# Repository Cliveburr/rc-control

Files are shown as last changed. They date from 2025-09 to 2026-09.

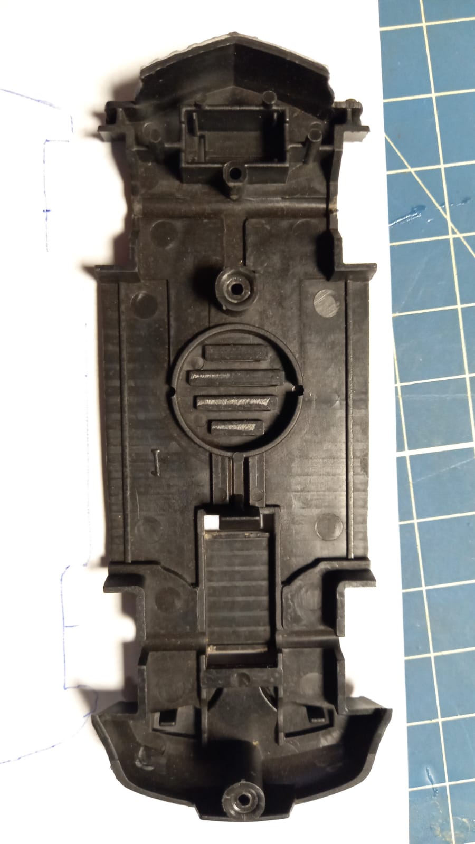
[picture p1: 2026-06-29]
blue-car-1_32/carcass_origin_real.jpeg

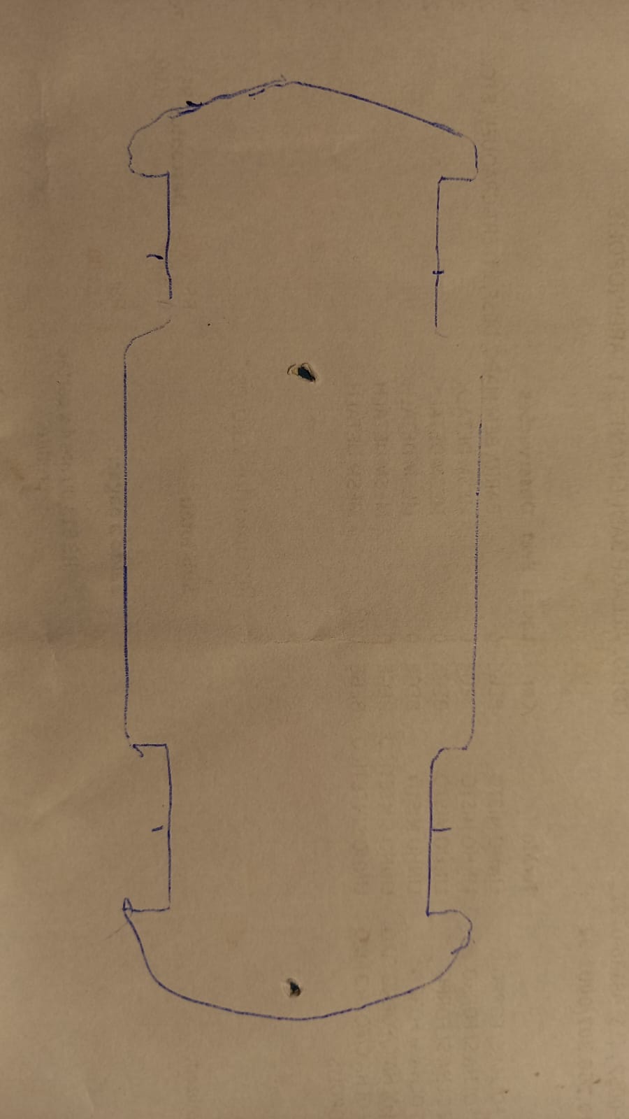
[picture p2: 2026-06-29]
blue-car-1_32/carcass_origin.jpeg

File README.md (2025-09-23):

# RC Control - Projeto ESP32 com Protocolo RCP Binário

## Protocolo RCP (RC Control Protocol)

O sistema utiliza **exclusivamente** o protocolo binário RCP para máxima performance:

- **4 bytes por comando** (vs 28 bytes JSON)
- **98% mais rápido** no processamento (10µs vs 500µs)
- **86% menos dados** transmitidos
- **Validação CRC8** para detecção de erros
- **WebSocket binário puro** sem fallbacks

## Funcionalidades

- ✅ Conexão WiFi (AP mode ou Station mode)
- ✅ Interface Web hospedada no ESP32
- ✅ Transmissão de vídeo via streaming
- ✅ **Sistema OTA (Over-The-Air) para atualizações de firmware**
- ✅ Configuração via interface web
- ✅ Armazenamento de configurações em memória não volátil

## Funcionalidades OTA Implementadas

### Configuração de Partições
- Partições configuradas para suportar OTA com rollback automático
- Duas partições de aplicação (ota_0 e ota_1) para atualizações seguras
- Partição otadata para controle do sistema OTA

### Interface Web para OTA
- **Aba OTA na configuração:** Acesse através do botão de configuração
- **Status do sistema:** Mostra partição atual em execução
- **Upload de firmware:** Envio de arquivos .bin através da interface web
- **Barra de progresso:** Acompanhamento visual do upload
- **Validação automática:** Verificação de integridade do firmware

### Endpoints HTTP para OTA
- `GET /ota/status` - Retorna informações sobre o estado atual das partições
- `POST /ota/upload` - Recebe e instala novo firmware

### Segurança e Rollback
- Rollback automático habilitado em caso de falha na inicialização
- Validação de firmware antes da instalação
- Reinicialização automática após atualização bem-sucedida

## Como Usar o Sistema OTA

1. **Acesse a interface web** do ESP32 através do navegador
2. **Clique no botão de configuração** (primeiro botão superior)
3. **Selecione a aba "OTA"** no menu lateral
4. **Verifique o status atual** do sistema
5. **Selecione o arquivo .bin** do novo firmware
6. **Clique em "Atualizar Firmware"** para iniciar o processo
7. **Aguarde o upload** (barra de progresso será exibida)
8. **O dispositivo reiniciará automaticamente** após a atualização

## Estrutura do Projeto

### Frontend (`/dev_html`)
- `index.html` - Interface principal com controles e configuração
- `script.js` - Lógica JavaScript incluindo funcionalidades OTA
- `style.css` - Estilos da interface
- `prod.js` - Script para gerar versão otimizada

### Backend ESP32 (`/main`)
- `src/main.c` - Inicialização do sistema e OTA
- `src/ota.c` - Implementação completa do sistema OTA
- `src/http_server.c` - Servidor web com endpoints OTA
- `src/config.c` - Gerenciamento de configurações
- `src/net.c` - Configuração de rede WiFi
- `inc/ota.h` - Definições do sistema OTA

## Compilação e Flash

```bash
# Configurar ambiente ESP-IDF
idf.py build

# Flash inicial (primeira vez)
idf.py flash

# Atualizações subsequentes podem ser feitas via OTA através da interface web
```

## Tarefas Completadas

- ✅ Salvar dados em memória não volátil
- ✅ Configurar WiFi (AP e Station mode)
- ✅ Servir HTML e WebSocket
- ✅ Transmitir vídeo via HTTP streaming
- ✅ **Sistema OTA completo com interface web**
- ✅ **Configuração de partições para OTA**
- ✅ **Upload de firmware via browser**
- ✅ **Rollback automático em caso de falha**

## Próximos Passos

- Melhorar qualidade da imagem
- Implementar controles de movimento
- Adicionar autenticação para OTA
- Logs detalhados do processo OTA

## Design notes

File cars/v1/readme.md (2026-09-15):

Versao v1 de chassis controlado por radio tradicional, 15 cm de comprimento, sem amortecedor, com o maximo de partes imprimiveis e usando componentes RC convencionais.

## Premissas da v1

- Comprimento alvo do chassi: 150 mm
- Arquitetura: full RC tradicional
- Alimentacao: LiPo 2S
- Direcao por servo padrao micro
- Tracao traseira simples
- Maximo de partes impressas, usando metal apenas onde faz sentido mecanico

## Arquitetura recomendada

### Conjunto base
- Radio: FlySky FS-I6X
- Receptor: micro receiver compativel com AFHDS 2A, 3 a 6 canais
- Motor: brushed tamanho 130, tensao 6 V a 7.4 V, eixo 2.0 mm
- ESC: brushed automotivo 2S com reverso e BEC 5 V integrado
- Servo: micro servo 5 V, entre 5 g e 9 g, torque minimo de 1.5 kg.cm
- Bateria: LiPo 2S de 450 mAh a 850 mAh
- Rolamentos: MR52ZZ, 2 x 5 x 2.5 mm
- Eixo traseiro: aco 2 mm
- Parafusos: M2 como padrao principal, M3 nos pontos estruturais

## Levantamento de componentes

### 1. Componentes principais

#### Motor de tracao
- Tipo: brushed tamanho 130
- Tensao de trabalho: 6.0 V a 7.4 V
- Tensao maxima: 8.4 V
- Eixo: 2.0 mm
- Faixa de corrente do conjunto: usar ESC de 10 A a 20 A
- Termo de busca: 130 brushed motor 8.4V 12000rpm

- Decidido:
MABUCHI FC-130RA-10300 Small 130 Motor DC 5V-12V 6V 9V High Speed18000RPM Micro 20mm Electric Motor DIY RC Toy Car Boat Model
https://pt.aliexpress.com/item/1005009147508182.html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

#### ESC
- Tipo: ESC brushed para carro
- Alimentacao: LiPo 2S
- Corrente continua: 10 A a 20 A
- Funcoes: frente, re, freio
- BEC integrado: 5 V
- Corrente minima do BEC: 1 A
- Termo de busca: brushed ESC 2S 10A reverse brake 5V BEC

- Decidido:
Mini ESC Brushed Electric Speed Controller ESC Brush Electronic Motor Speed Controller Module 30A 4-8V For RC Car
https://pt.aliexpress.com/item/1005009648276627.html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

#### Servo de direcao
- Alimentacao: 5 V
- Peso: 5 g a 9 g
- Torque minimo: 1.5 kg.cm
- Torque ideal: 1.8 kg.cm a 2.5 kg.cm
- Velocidade: 0.10 s a 0.14 s por 60 graus
- Tipo de engrenagem: nylon ou metal
- Termo de busca: 5V micro servo 9g 2kg

- Decidido:
MG90S Servo 1/4/10 Pcs Metal Gear Digital 9g Servo For RC Helicopter Airplane Boat Car RC Robot
https://pt.aliexpress.com/item/1005006860780474.html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

#### Bateria
- Tipo: LiPo 2S
- Tensao nominal: 7.4 V
- Tensao maxima: 8.4 V
- Capacidade recomendada: 650 mAh a 850 mAh
- Taxa de descarga: 30C ou maior
- Conector: XT30
- Termo de busca: 2S LiPo 850mAh 30C XT30

#### Receptor
- Tipo: micro receiver compativel com FlySky AFHDS 2A
- Canais: 3 a 6
- Alimentacao: 4.8 V a 6.0 V pelo BEC do ESC
- Saida: PWM padrao RC
- Quantidade para compra: 1 unidade
- Termo de busca: FlySky AFHDS 2A micro receiver

#### Rolamentos
- Modelo: MR52ZZ
- Medida: 2 x 5 x 2.5 mm
- Tipo: blindado metal
- Uso previsto: eixo traseiro e pivots dianteiros
- Quantidade minima para compra: 10 unidades
- Quantidade mais segura: 20 unidades
- Termo de busca: MR52ZZ 2x5x2.5mm bearing

### 2. Itens mecanicos muito provaveis

#### Eixos
- Eixo traseiro: haste de aco 2 mm
- Linkagens: haste de 1.0 mm a 1.2 mm

#### Engrenagens
- Pinhao: modulo 0.5, 10T a 12T, furo 2.0 mm
- Coroa: modulo 0.5, 48T a 64T
- Relacao inicial: 5:1 a 7:1
- Termo de busca: 0.5 mod pinion 2mm bore
- Termo de busca: 0.5 mod spur gear 48T 64T

#### Cubos e fixacao de roda
- Cubos: eixo 2 mm com prisioneiro M2
- Rodas: 22 mm a 26 mm de diametro
- Largura sugerida: 8 mm a 12 mm

#### Linkagem de direcao
- Arame 0.8 mm a 1.2 mm
- Terminal M2 ou dobra tipo Z
- Servo horn compativel com o servo escolhido

### 3. Parafusos e fixadores

Voce ja tem M2 e M3, e para um chassi de 15 cm isso ainda cobre o projeto.

#### O que provavelmente sera usado de verdade
- M2: fixacao do servo, suportes pequenos, manga de eixo, tampa de transmissao, prisioneiros e partes finas impressas
- M3: longarinas, uniao principal do chassi, suporte de bateria, fixacao do ESC e do receptor se houver base mais robusta

#### Comprimentos uteis
- M2 x 4, 6, 8, 10 e 12 mm
- M3 x 6, 8, 10, 12 e 16 mm
- Porcas M2 e M3
- Arruelas M2 e M3
- Insertos roscados pequenos para plastico, se quiser manutencao melhor

## Regulacao de tensao

- Receptor: 5 V pelo BEC do ESC
- Servo: 5 V pelo BEC do ESC
- Regulador extra: nao necessario se o ESC tiver BEC integrado

## Lista de compra recomendada

### Comprar agora
- 2 a 3 motores brushed tamanho 130 para 2S, eixo 2.0 mm
- 1 a 2 ESCs brushed 2S com reverso e BEC 5 V
- 2 micro servos 5 V entre 5 g e 9 g, acima de 1.5 kg.cm
- 2 a 3 baterias LiPo 2S entre 650 mAh e 850 mAh, 30C ou maior, com XT30
- 1 micro receiver compativel com FlySky AFHDS 2A
- 10 a 20 rolamentos MR52ZZ 2 x 5 x 2.5 mm
- 2 hastes de aco 2 mm
- 1 kit de pinhoes 0.5M para eixo 2.0 mm
- 1 kit de coroas 0.5M 48T a 64T
- 1 jogo de cubos de roda para eixo 2 mm com prisioneiro M2
- 1 conjunto de linkagem de direcao 0.8 mm a 1.2 mm
- 1 jogo de conectores XT30 e fio de silicone 20 AWG a 24 AWG

### Comprar so se faltar no estoque
- Porcas M2 e M3
- Arruelas M2 e M3
- Parafusos M2 curtos em varios comprimentos
- Parafusos M3 medio e longos
- Espacadores plastico ou metal
- Servo horn extra

## BOM base

- FlySky FS-I6X
- Micro receiver compativel com AFHDS 2A
- Motor brushed tamanho 130, eixo 2.0 mm
- ESC brushed 2S com reverso e BEC 5 V
- Micro servo 5 V entre 5 g e 9 g
- Bateria LiPo 2S 650 mAh a 850 mAh com XT30
- Rolamentos MR52ZZ 2 x 5 x 2.5 mm
- Eixo de aco 2 mm
- Pinhao 0.5M 10T a 12T, furo 2.0 mm
- Coroa 0.5M 48T a 64T
- Cubos de roda 2 mm com prisioneiro M2
- Rodas 22 mm a 26 mm
- Linkagem 0.8 mm a 1.2 mm
- Parafusos M2 e M3

- Pneu(Tire)
- Roda(Wheel), tem q ter o furo central e o encaixe xegagonal para encaixar no cubo da roda
- Cubo da roda(WheelHub), da suporte para a rosca da roda, o eixo de roda passa por ela e ela fica encostada com espaçador no rolamento do manga do eixo
- Manga do eixo(SteeringKnuckle)
- HubCarrier

V1

Eixo 2mm
Rolamento 2x5x2.5mm

- Comprar cossinete 2mm

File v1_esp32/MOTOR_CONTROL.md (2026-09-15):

# Motor Control System Documentation

## Overview

This document describes the motor control system implemented for the RC Control project. The system provides a Hardware Abstraction Layer (HAL) that supports multiple motor drivers with easy driver switching.

## Features

- **Hardware Abstraction Layer (HAL)**: Easily switch between different motor drivers
- **DRV8833 Driver**: Full implementation with PWM control
- **Multiple Control Modes**: Forward, Reverse, Brake, and Free running
- **Speed Control**: -100 to +100 range (full reverse to full forward)
- **Web Interface Integration**: Control via HTTP commands
- **Status Monitoring**: Real-time motor state via system info endpoint
- **Configurable Parameters**: GPIO pins, PWM settings, and control modes

## Architecture

### Motor Control HAL (`motor_control.h/c`)

The main HAL provides a unified interface for all motor drivers:

```c
// Initialize motor control system
esp_err_t motor_control_init(void);

// Set motor speed (-100 to +100)
esp_err_t motor_control_set_speed(int speed);

// Set motor mode directly
esp_err_t motor_control_set_mode(motor_mode_t mode);

// Stop motor immediately
esp_err_t motor_control_stop(void);

// Get current motor state
esp_err_t motor_control_get_state(motor_state_t *state);
```

### DRV8833 Driver (`motor_drv8833.h/c`)

Specific implementation for DRV8833 dual H-bridge motor driver:

- **GPIO Pins**: GPIO16 (IN1), GPIO17 (IN2)
- **PWM Frequency**: 1kHz (configurable)
- **Resolution**: 10-bit (0-1023)
- **Control Method**: Direct PWM on IN1/IN2 pins

## Configuration

### Hardware Configuration (`motor_drv8833.h`)

```c
// GPIO pins for DRV8833
#define DRV8833_IN1_PIN         16  // GPIO16 for IN1
#define DRV8833_IN2_PIN         17  // GPIO17 for IN2

// PWM configuration
#define DRV8833_LEDC_FREQUENCY      1000                // 1kHz PWM frequency
#define DRV8833_LEDC_DUTY_RES       LEDC_TIMER_10_BIT   // 10-bit resolution

// Control modes
#define DRV8833_BRAKE_MODE_HIGH     1  // 1 = IN1=HIGH, IN2=HIGH for brake
#define DRV8833_FREE_MODE_LOW       1  // 1 = IN1=LOW, IN2=LOW for free
```

### Driver Selection (`motor_control.h`)

```c
// Change this to switch motor drivers
#define MOTOR_ACTIVE_DRIVER     MOTOR_DRIVER_DRV8833
```

## Motor Control Modes

| Mode | Description | DRV8833 Configuration |
|---|---|---|
| **MOTOR_MODE_FORWARD** | Motor rotating forward | IN1=PWM, IN2=LOW |
| **MOTOR_MODE_REVERSE** | Motor rotating in reverse | IN1=LOW, IN2=PWM |
| **MOTOR_MODE_BRAKE** | Motor braking (short circuit) | IN1=HIGH, IN2=HIGH |
| **MOTOR_MODE_FREE** | Motor free running (no power) | IN1=LOW, IN2=LOW |

## Web Interface Integration

### Speed Control Command

The motor responds to speed commands sent via WebSocket:

```json
{
  "command": "speed",
  "value": 75
}
```

Where `value` ranges from -100 to +100:
- **-100**: Full reverse
- **0**: Stop (brake mode)
- **+100**: Full forward

### System Status

Motor status is included in the `/api/system/info` endpoint:

```json
{
  "motor": {
    "enabled": true,
    "speed": 75,
    "mode": 0,
    "mode_str": "forward",
    "active": true
  }
}
```

## Usage Examples

### Basic Motor Control

```c
#include "motor_control.h"

void app_main(void) {
    // Initialize motor control
    motor_control_init();
    
    // Set forward speed at 50%
    motor_control_set_speed(50);
    
    // Wait 2 seconds
    vTaskDelay(2000 / portTICK_PERIOD_MS);
    
    // Set reverse speed at 30%
    motor_control_set_speed(-30);
    
    // Wait 2 seconds
    vTaskDelay(2000 / portTICK_PERIOD_MS);
    
    // Stop motor
    motor_control_stop();
}
```

### Direct Mode Control

```c
// Set motor to free running mode
motor_control_set_mode(MOTOR_MODE_FREE);

// Set motor to brake mode
motor_control_set_mode(MOTOR_MODE_BRAKE);
```

### Get Motor Status

```c
motor_state_t state;
if (motor_control_get_state(&state) == ESP_OK) {
    printf("Speed: %d, Mode: %d, Enabled: %s\n", 
           state.speed, state.mode, state.enabled ? "Yes" : "No");
}
```

## Adding New Motor Drivers

To add support for a new motor driver (e.g., L298N):

1. **Create header file**: `motor_l298n.h`
2. **Create implementation**: `motor_l298n.c`
3. **Implement driver interface**:
   ```c
   const motor_driver_interface_t* l298n_get_interface(void);
   ```
4. **Add driver type**: Add `MOTOR_DRIVER_L298N` to `motor_driver_type_t`
5. **Update driver selection**: Modify `MOTOR_ACTIVE_DRIVER` in `motor_control.h`

## Pin Usage Summary

| Component | GPIO | Function |
|---|---|---|
| Motor IN1 | GPIO16 | PWM control (DRV8833) |
| Motor IN2 | GPIO17 | PWM control (DRV8833) |
| Servo | GPIO4 | PWM control |
| LED Light | GPIO2 | Digital output |
| LED Horn | GPIO14 | Digital output |
| Battery Monitor | GPIO34 | ADC input |

## Troubleshooting

### Motor Not Responding

1. Check `ENABLE_MOTOR_CONTROL` is set to 1 in `project_config.h`
2. Verify GPIO pins are not conflicting with other peripherals
3. Check motor driver initialization in serial output
4. Verify motor driver power supply

### Compilation Errors

1. Ensure all header files are included properly
2. Check driver selection configuration
3. Verify ESP-IDF version compatibility

### Performance Issues

1. Adjust PWM frequency in driver configuration
2. Check for GPIO conflicts
3. Monitor system load and memory usage

## Future Enhancements

- **Multiple Motor Support**: Extend HAL for multiple motors
- **Encoder Feedback**: Add position/speed feedback
- **PID Control**: Implement closed-loop control
- **Safety Features**: Current limiting, thermal protection
- **Additional Drivers**: L298N, TB6612FNG, etc.

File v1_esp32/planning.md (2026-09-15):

Projeto ESP32 para controle de carro/drone/aviação remoto.

- Conexão por Wifi ou Bluetooth
- Update do firmware por OTA (Over the Air)
- View em HTML hospedada no proprio ESP32
- Comandos via Websocket

Projeto Html:
    Folder: /dev_html
    - Todo HTML deve ficar no único arquivo "index.html"
    - Todo javascript deve ficar no único arquivo "script.js"
    - Todo CSS deve ficar no único arquivo "style.css"
    - Maxima otimização do JS e CSS
    - Preparado para Landscape mode

Project ESP32:
    Folder: /main
    - Arquivo /main/wwwroot/index.html é gerado pelo script "\dev_html> node run prod"
    - O OTA vai ser enviado pelo HTML
    - Os LED devem sempre estar configurado no modo Sinking (Dreno de corrente – Negativo direto no LED)

Views:
    Main:
        Divisão por colunas
            Primeira coluna um botão de controle de velocidade do lado esquerdo
            Resto das colunas
                Divisão por linhas
                    Linha do topo para botões
                        Sequencia de botões de uso geral
                        No canto esquero um botão abre tela de configuração
                    Linha alinha abaixo
                        Botão de controle de direção alinhado a direita

    Configuration:
        Card - Configuration
        No body um tab com itens a esquerda, itens:
            General
            Wifi
            OTA
        Tab General:
            Botão de escolha da conexão, Bluetooth ou WIFI
        Tab Wifi:
            Campo para entrar o nome do WIFI
            Campo para entrar a senha do WIFI
            Botão para Gravar
        Tab OTA:
            Botão para selecionar o arquivo .bin para fazer upload
            Botão para Atualizar

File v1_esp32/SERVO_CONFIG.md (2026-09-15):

# Configuração do Servo GH-S37D

## Conexões GPIO

### Servo GH-S37D (3.7g Mini Micro Servo)
- **GPIO4** - Sinal de controle PWM do servo
- **3.3V** - Alimentação VCC (compatível com 1S LiPo 3.7V)
- **GND** - Terra comum

### Esquema de Conexão
```
ESP32        GH-S37D Servo
GPIO4   -->  Sinal (amarelo/branco)
3.3V    -->  VCC (vermelho)
GND     -->  GND (marrom/preto)
```

## Especificações Técnicas

### Servo GH-S37D
- **Tensão**: 3.0V - 4.2V (ideal para 1S LiPo)
- **Peso**: 3.7g
- **Torque**: ~0.8kg.cm
- **Velocidade**: ~0.10s/60°
- **Controle**: PWM padrão (50Hz, 1-2ms pulse width)

### Configuração PWM
- **Frequência**: 50Hz (período de 20ms)
- **Largura de pulso**:
  - 1.0ms = mínimo configurado
  - 1.5ms = centro
  - 2.0ms = máximo configurado
- **Importante**: esses pulsos definem o range elétrico enviado ao servo. O ângulo mecânico real depende do modelo do servo, da tensão e da linkagem. Em muitos microservos, 1.0-2.0ms resulta em algo perto de 90° totais, ou cerca de 45° para cada lado a partir do centro.
- **Resolução**: 13 bits (8192 níveis)
- **Timer LEDC**: TIMER_1
- **Canal LEDC**: CHANNEL_1

## Comando de Controle

### Via WebSocket
```json
{
  "type": "wheels",
  "value": 0
}
```

**Valores do comando:**
- `-100` = pulso mínimo configurado
- `0` = centro
- `+100` = pulso máximo configurado

### Função de Controle
```c
esp_err_t servo_control_set_position(int position);
```

**Parâmetros:**
- `position`: Valor entre -100 e +100
- **Retorno**: `ESP_OK` se bem-sucedido

## Instalação Física

### Montagem
1. Fixar o servo na estrutura do chassi usando parafusos M2
2. Conectar o braço servo (servo horn) ao sistema de direção
3. Ajustar linkagem para que posição central corresponda a rodas retas

### Linkagem de Direção
- Use barras de ligação rígidas (pushrods) de 0.8-1.0mm
- Terminais esféricos (ball links) M2 para conexões articuladas
- Comprimento da linkagem deve permitir curso completo sem travamento

### Alimentação
- O servo pode ser alimentado diretamente da bateria 1S LiPo (3.7V)
- Consumo típico: 50-150mA em operação normal
- Pico de corrente: até 500mA durante movimento rápido

## Calibração

### Valores de Trim
Se necessário ajustar o centro mecânico:
1. Modificar `SERVO_CENTER_PULSE_WIDTH` em `servo_control.h`
2. Valores típicos: 1450-1550μs dependendo do servo

### Limitação de Curso
Para evitar danos mecânicos:
1. Ajustar `SERVO_MIN_PULSE_WIDTH` e `SERVO_MAX_PULSE_WIDTH`
2. Testar movimento completo antes de finalizar montagem
3. Confirmar o curso real do servo antes de assumir 180° totais com 1.0-2.0ms

## Troubleshooting

### Servo não responde
- Verificar conexões GPIO4, 3.3V e GND
- Confirmar tensão de alimentação (3.0-4.2V)
- Verificar logs no monitor serial

### Movimento irregular
- Verificar interferência eletromagnética
- Adicionar capacitor de filtro (100μF) na alimentação
- Afastar fios do servo dos fios do motor principal

### Consumo excessivo
- Verificar se linkagem não está travando
- Reduzir carga mecânica no servo
- Verificar alinhamento das peças móveis

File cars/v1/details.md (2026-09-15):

manga de eixo
cubo da roda
mancal do eixo
stub axle ou eixo fixo da roda na dianteira
Se eu fosse fechar a arquitetura agora, eu faria assim:

Traseira: 2x MR52ZZ no chassi, eixo de 2 mm, cubo preso no eixo, roda parafusada no cubo.
Dianteira: 2x MR52ZZ por roda, dentro do cubo da roda, girando em um eixo fixo preso na manga de eixo.

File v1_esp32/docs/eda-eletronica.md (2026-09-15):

https://kicad.org/download

Extensões de diagrama no VSCODE

Draw.io (hediet.vscode-drawio)
Comunidade: Muito grande — diagrams.net é amplamente usado; a extensão do Hediet é popular (repositório com milhares de stars).
Maturidade: Madura e estável, pensada para diagramas e documentação.
Atividade: Repositório ativo, releases e CI; mantém atualizações periódicas.
Componentes: Biblioteca de símbolos elétricos disponível; você pode importar/colar SVGs ou criar símbolos para ESP32, drivers e buck converters, mas não há footprint/netlist.
Exportação: PNG, SVG, PDF, XML (.drawio) e .drawio.png com dados embutidos — ótimo para documentação, não para fabricação.
Quando usar: se quer desenhar esquemas e guardar junto ao código no VSCode rapidamente (documentação/diagramas de fiação).

Circuit Diagram (circuitdiagram-vscode / circuit-diagram libraries)
Comunidade: Menor que draw.io; projeto nicho focado em diagramas eletrônicos simples.
Maturidade: Leve e suficiente para diagramas técnicos em docs, não EDA.
Atividade: atividade moderada/irregular (projetos menores).
Componentes: símbolos eletrônicos básicos; customização possível mas biblioteca limitada (ESP32 provavelmente como símbolo genérico).
Exportação: SVG/PNG/HTML; sem netlist nem gerbers.
Quando usar: se prefere diagramas rápidos em texto/markdown ou integração direta com docsites.

KiCad + KiCad Studio (oaslananka/kicad-studio para VS Code)
Comunidade: Muito grande — KiCad é ferramenta EDA open-source padrão; forte comunidade e bibliotecas extensas.
Maturidade: Produção/industrial — adequado para criar esquemáticos e preparar fabricação (PCB).
Atividade: KiCad é ativamente desenvolvido; a extensão KiCad Studio integra o workflow ao VS Code (repositorio separado, evolução mais recente).
Componentes: Bibliotecas extensas (muitos MCU/modules, drivers, conversores). ESP32 e drivers típicos têm símbolos/footprints comunitários; se faltar, cria-se o símbolo/footprint.
Exportação: Netlist, Gerber/Drill, BOM, STEP/3D, formatos industriais — ideal para passar a outro programa ou mandar fabricar.
Quando usar: se pretende, no futuro, fabricar PCBs ou precisar de netlist/BOM — é a opção mais completa (exige instalação do KiCad e curva de aprendizado).

SchemDraw (biblioteca Python)
Comunidade: Nicho (científico/descritivo), menor que opções acima.
Maturidade: Estável para criar imagens via código.
Atividade: mantido, bom para automação de diagramas.
Componentes: Shapes programáticos; dá para representar ESP32/stepper, mas sem footprint/netlist.
Exportação: SVG, PDF, PNG (gerado por script).
Quando usar: se quer gerar diagramas por script/automação (não interativo no VS Code).

Fritzing
Comunidade: Firme na comunidade hobbyista/maker; menos usado profissionalmente.
Maturidade: Fácil para breadboard/diagrama de ligação; UI feita para iniciantes.
Atividade: menor que KiCad; desenvolvimento e manutenção mais lentos.
Componentes: muitas peças comunitárias; ESP32 e módulos hobby geralmente disponíveis ou importáveis.
Exportação: Pode exportar PCB e gerar Gerbers (útil para fabricar), mas as bibliotecas/qualidade de footprints são mais limitadas que KiCad.
Quando usar: protótipos rápidos estilo breadboard e documentação para makers; menos recomendado para produção.
Recomendação curta

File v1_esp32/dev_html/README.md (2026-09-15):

# RC Control - Interface Web com Protocolo RCP Binário Puro

## Sobre a Interface

Esta é a interface web de controle do carrinho RC que utiliza **exclusivamente** o **RCP (RC Control Protocol)** - um protocolo binário customizado para comunicação ultra-eficiente.

## Arquivos

- `index.html` - Interface principal de controle
- `style.css` - Estilos visuais  
- `script.js` - **Lógica JavaScript com RCP Client puro**

## Protocolo RCP Puro

A interface utiliza **APENAS** o protocolo RCP binário:

### ✅ **Performance Ultra-Otimizada:**
- **4 bytes por comando** vs 28 bytes JSON (86% redução)
- **10µs processamento** vs 500µs JSON (98% mais rápido)
- **Validação CRC8** para detecção de erros
- **Protocolo binário puro** - sem fallbacks ou legacy code

### ✅ **Comunicação Limpa:**
```javascript
// Apenas comandos RCP binários
rcpClient.sendMotorCommand(-85);    // 4 bytes
rcpClient.sendServoCommand(45);     // 4 bytes  
rcpClient.sendHornCommand(true);    // 4 bytes
rcpClient.sendLightCommand(false);  // 4 bytes
```

### ✅ **Funções de Debug:**
```javascript
// No console do navegador
showRCPStats(); // Mostra estatísticas do protocolo
```

## Como Testar

1. **Compile e flash o ESP32** com suporte RCP
2. **Conecte na rede WiFi** do ESP32
3. **Acesse** `http://192.168.4.1`
4. **Controle o carrinho** normalmente
5. **Abra F12 Console** e digite `showRCPStats()` para ver performance

## Logs de Conexão

Quando conectar, você verá no console:
```
WebSocket connected for control commands
RCP Client v1.0 initialized
RCP Client initialized and ready
```

## Comandos de Controle

### **Motor (Speed):**
- Controle vertical esquerdo
- Range: -100 (ré máxima) a +100 (frente máxima)
- **RCP**: 4 bytes binários

### **Servo (Wheels):**
- Controle horizontal inferior
- Range: -100 (esquerda máxima) a +100 (direita máxima)  
- **RCP**: 4 bytes binários

### **Horn:**
- Botão de buzina (alto-falante)
- Estados: ON/OFF
- **RCP**: 4 bytes binários

### **Light:**
- Botão de luz (lâmpada)
- Estados: ON/OFF
- **RCP**: 4 bytes binários

## Requisitos do Sistema

### **ESP32:**
- ✅ **Firmware com suporte RCP obrigatório**
- ✅ **Protocolo binário único**
- ❌ **Sem suporte a JSON legacy**

### **Interface Web:**
- ✅ **WebSocket binário obrigatório**
- ✅ **Conectividade automática**
- ❌ **Sem fallback para JSON**

## Monitoramento de Performance

### **Estatísticas em Tempo Real:**
```javascript
// Console do navegador
showRCPStats();

// Saída esperada
=== RCP Protocol Statistics ===
Commands Sent: 1247
Responses Received: 156  
Errors: 0
Success Rate: 100.0%
==============================
```

### **Logs de Debug:**
Para habilitar logs detalhados, altere no `script.js`:
```javascript
const DEBUG = true; // Mostra logs detalhados
```

## Benefícios do RCP

### **Para Usuários:**
- ✅ **Resposta mais rápida** dos controles
- ✅ **Menor latência** na comunicação
- ✅ **Menos problemas** de conectividade
- ✅ **Bateria dura mais** (menos processamento)

## Troubleshooting

### **Conexão não funciona:**
1. Verificar se ESP32 foi compilado com suporte RCP
2. Verificar logs no console: deve aparecer "RCP Client initialized"
3. ESP32 deve ter protocolo RCP compilado (sem JSON legacy)

### **Performance não otimizada:**
1. Verificar `showRCPStats()` - deve mostrar commands sent > 0
2. Verificar se errors = 0
3. Todos os comandos devem ser binários (4 bytes cada)

### **Problemas de conectividade:**
1. RCP inclui validação CRC8 - detecta problemas de rede
2. Reconnect automático mantido
3. Apenas frames binários são aceitos

**O protocolo RCP puro oferece máxima performance sem complexidade de fallbacks!** 🚀

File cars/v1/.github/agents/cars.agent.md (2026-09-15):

---
name: cars
description: Assistente para criação de carro radio controlado impresso 3D
tools: [read/readFile, read/viewImage, edit/createDirectory, edit/createFile, edit/editFiles, search/listDirectory, search/textSearch, web/fetch, freecad/create_document, freecad/create_object, freecad/delete_object, freecad/edit_object, freecad/execute_code, freecad/get_object, freecad/get_objects, freecad/get_parts_list, freecad/get_view, freecad/insert_part_from_library, freecad/list_documents, brave-search/brave_local_search, brave-search/brave_web_search] 'freecad/*']
---

Esta workspace é para criação de modelos de carros radio controlado com o máximo de peças impressa em 3D, seu papel é auxiliar o usuário a resolver os detalhes dos projetos.

Use o documento - [figure_process.md](../../figure_process.md) como centro de informações.

O contéudo dos documentos sempre em Português(PT-BR) porém considere nomenclaturas e palavras chaves em Ingles, assim como as versões tanto do Blender, FreeCAD e do BambuLab Slicer tudo em ingles.

Use o brave_search quando precisar fazer pesquisas pela internet, sempre efetuando apenas uma chamada por vez.

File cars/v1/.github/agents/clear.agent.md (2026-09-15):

---
name: clear
description: Agent limpo para duvidas gerais
tools: [web/fetch, 'brave-search/*']
---

Você é um assistente para responde as duvidas do usuário, seja direto, não proponha alterantivas se não for solicitado.

Use o brave_search quando precisar fazer pesquisas pela internet, sempre efetuando apenas uma chamada por vez.

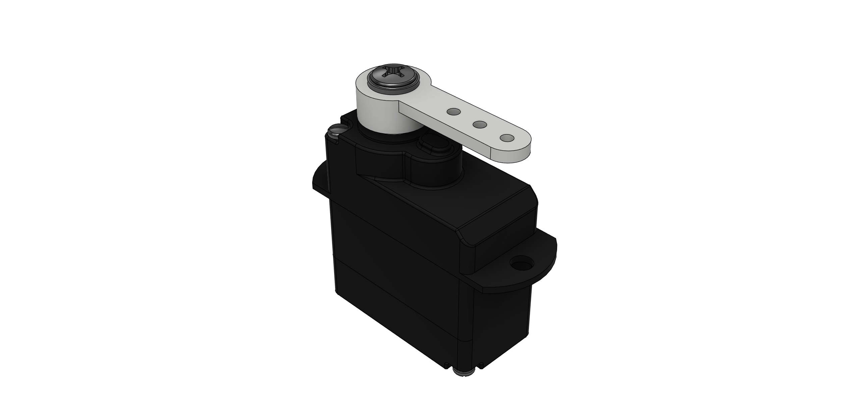
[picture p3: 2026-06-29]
3dmodels/servos/Mini 2g Servo Motor/Mini 2g Servo Motor Top.png

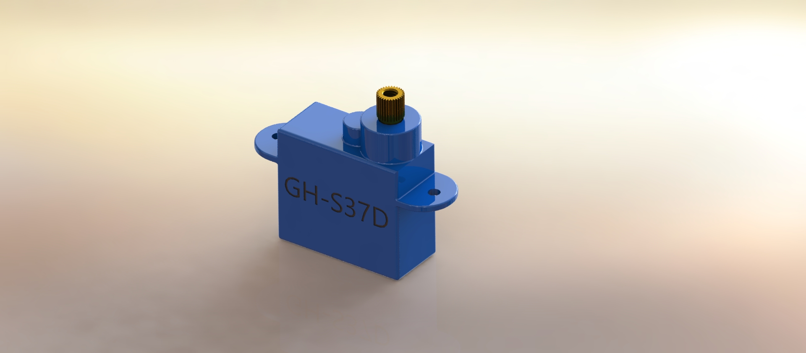
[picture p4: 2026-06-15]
3dmodels/servos/GH-S37D/servo GH-S37D.JPG

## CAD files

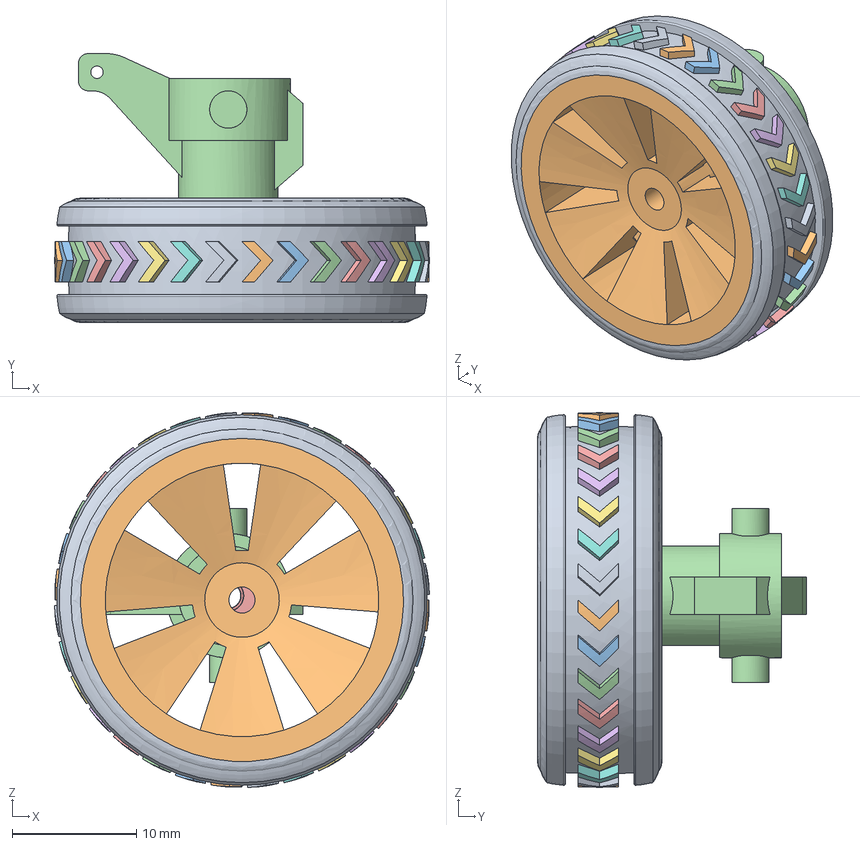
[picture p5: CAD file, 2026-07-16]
cars/v1/chassis/ChassiAssembly.FCStd
30.2 x 21.6 x 30.2 mm
Tire_2a_10l_V1
Tire_2a_10l_V001
Tire_2a_10l_V002
Tire_2a_10l_V003
Tire_2a_10l_V004
Tire_2a_10l_V005
Tire_2a_10l_V006
Tire_2a_10l_V007
Tire_2a_10l_V008
Tire_2a_10l_V009
Tire_2a_10l_V010
Tire_2a_10l_V011
Tire_2a_10l_V012
Tire_2a_10l_V013
Tire_2a_10l_V014
Tire_2a_10l_V015
Tire_2a_10l_V016
Tire_2a_10l_V017
Tire_2a_10l_V018
Tire_2a_10l_V019
Tire_2a_10l_V020
Tire_2a_10l_V021
Tire_2a_10l_V022
Tire_2a_10l_V023
Tire_2a_10l_V024
Tire_2a_10l_V025
Tire_2a_10l_V026
Tire_2a_10l_V027
Tire_2a_10l_V028
Tire_2a_10l_V029
Tire_2a_10l_V030
Tire_2a_10l_V031
Tire_2a_10l_V032
Whells_26d_10l_V1
WhellHubV1
SteeringKnuckleV1
MR52ZZ 2x5x2.5mm

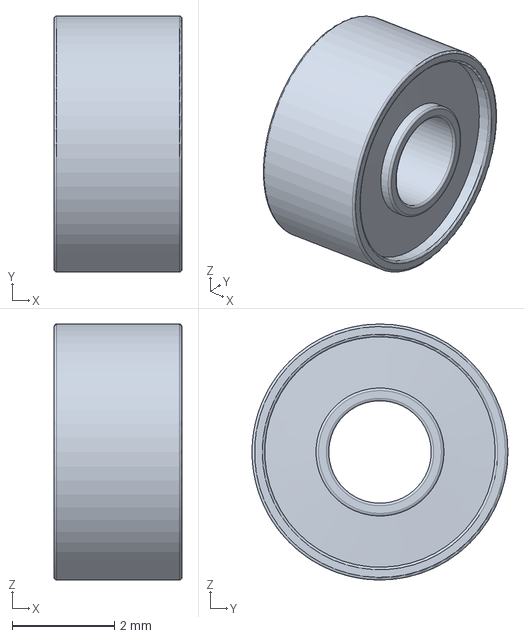
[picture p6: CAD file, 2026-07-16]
3dmodels/bears/MR52ZZ 2x5x2.5mm.FCStd
2.50 x 5.00 x 5.00 mm

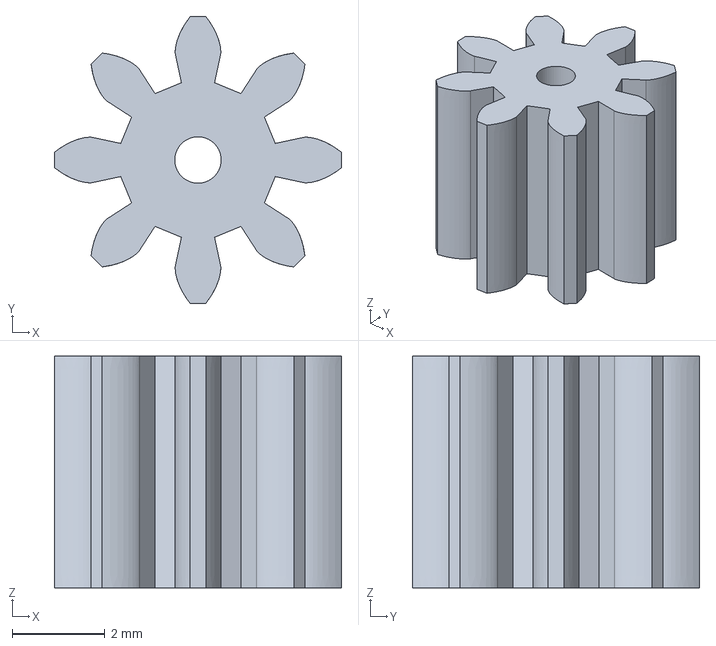
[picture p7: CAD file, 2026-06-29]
3dmodels/gears/GearsModels.FCStd
6.19 x 6.19 x 5.00 mm

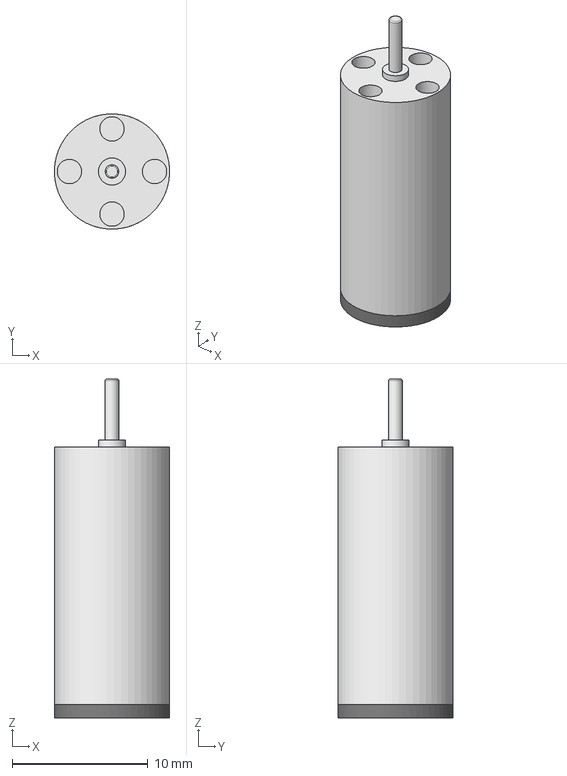
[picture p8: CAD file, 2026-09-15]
3dmodels/motors/8520 Coreless Brshed motor.step
8.50 x 8.50 x 25.0 mm

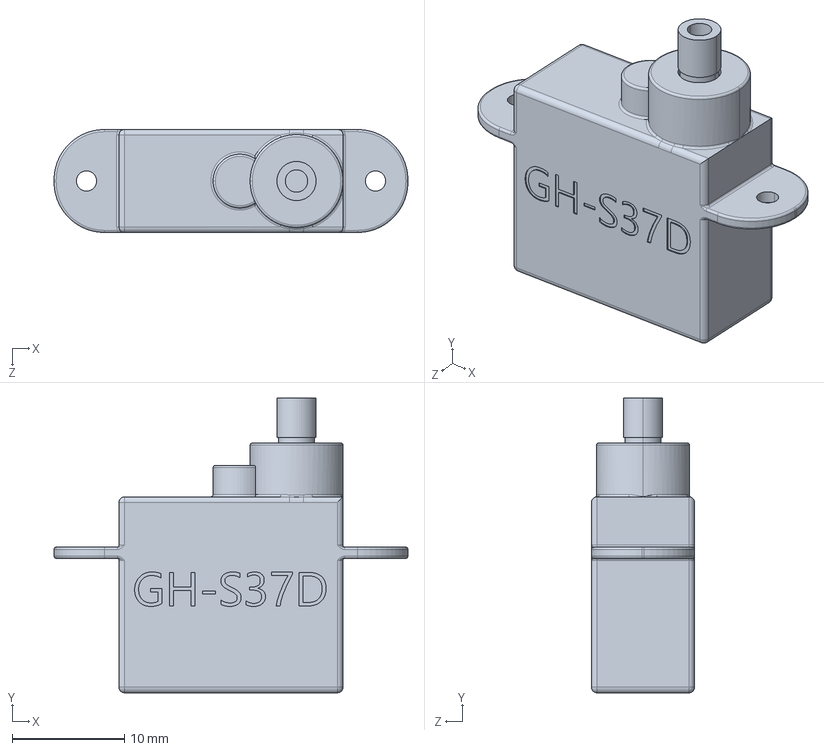
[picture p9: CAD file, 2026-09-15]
3dmodels/servos/GH-S37D/Gh-S37D Servo.STEP
31.6 x 26.3 x 9.20 mm

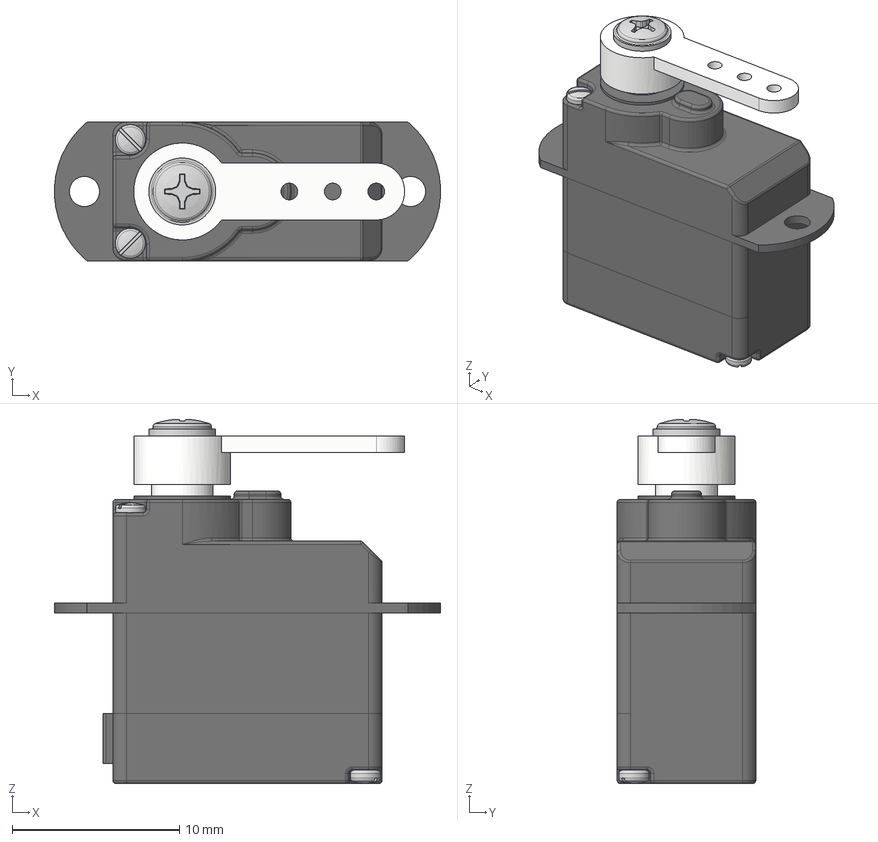
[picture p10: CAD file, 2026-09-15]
3dmodels/servos/Mini 2g Servo Motor/Mini 2g Servo Motor.step
23.1 x 8.30 x 21.8 mm
Shaft
Horn
Screw

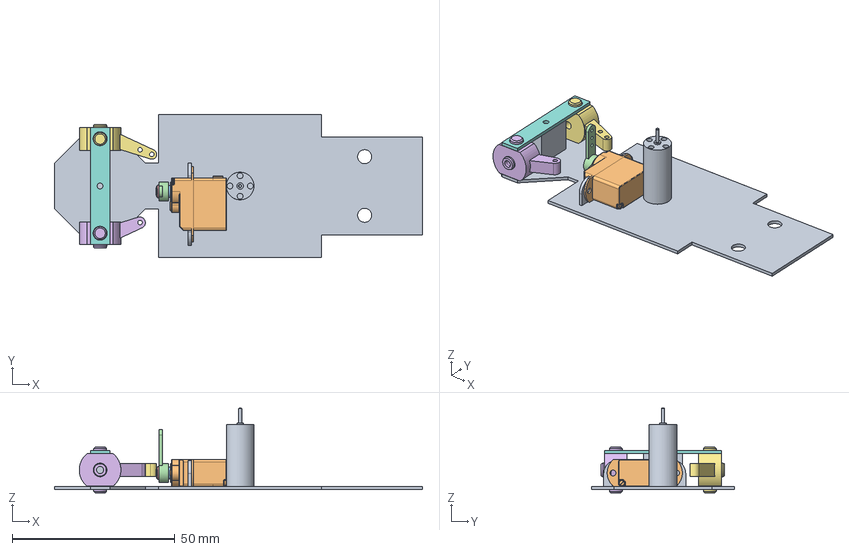
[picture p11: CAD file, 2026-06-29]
blue-car-1_32/BlueCar132Carcass.FCStd
113.0 x 44.0 x 26.0 mm
BaseEncaixe
Shaft
Horn
Screw
CuboDirecaoRodaEsquerda
CuboDirecaoRodaDireita
TampaDirecao
8520 Coreless Motor v3
8520 Coreless Motor v001

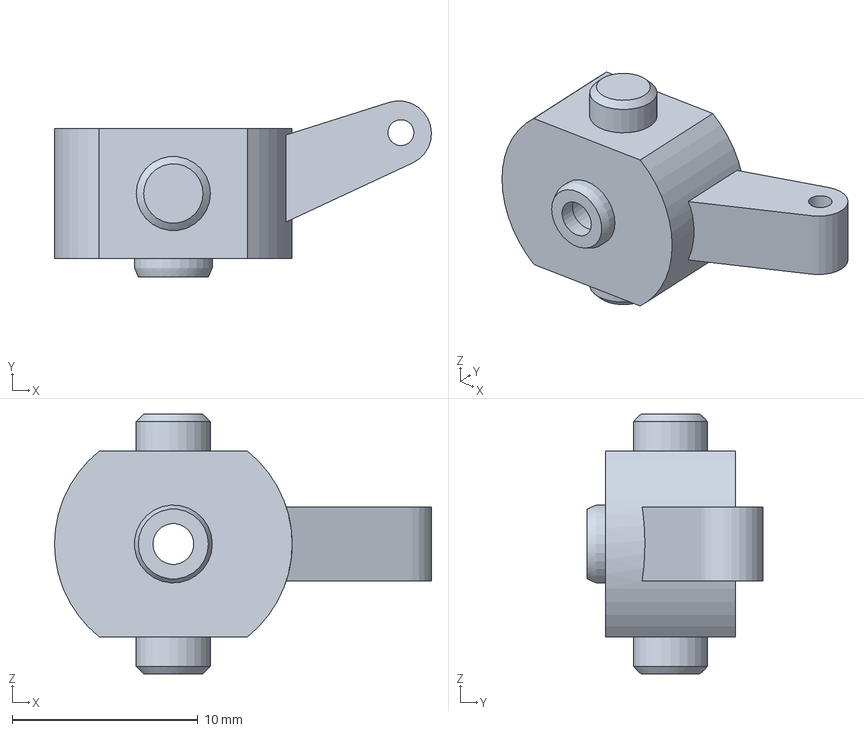
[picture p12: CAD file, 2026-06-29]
blue-car-1_32/prints/BlueCar132Carcass-CuboDirecaoRodaEsquerda.3mf
20.3 x 9.49 x 14.0 mm

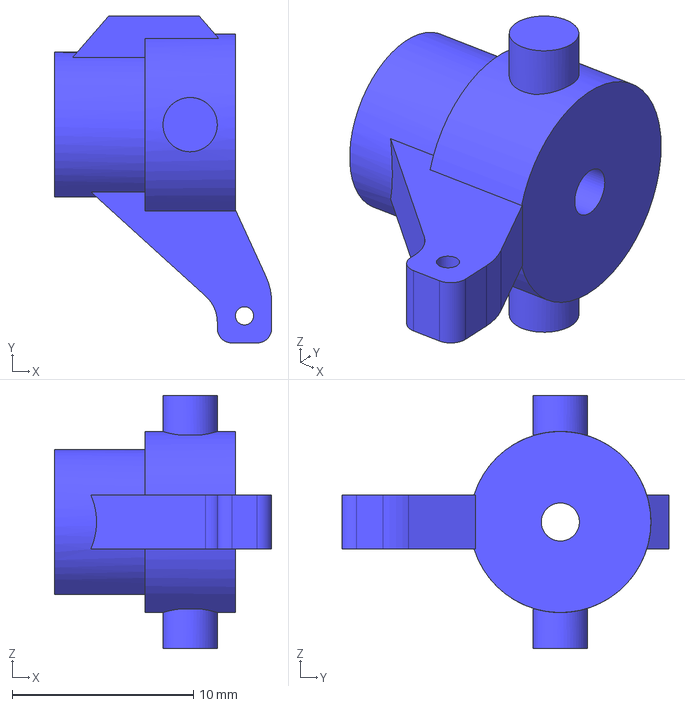
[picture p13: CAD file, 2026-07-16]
cars/v1/chassis/steps/SteeringKnuckle-SteeringKnuckleV1.step
12.0 x 18.1 x 14.0 mm

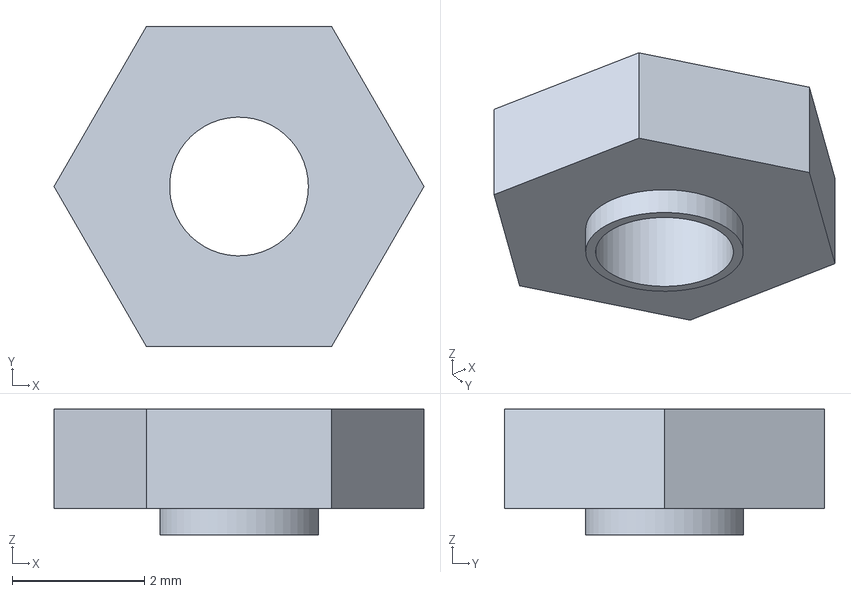
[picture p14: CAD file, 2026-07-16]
cars/v1/chassis/WhellHub.FCStd
5.60 x 4.85 x 1.90 mm

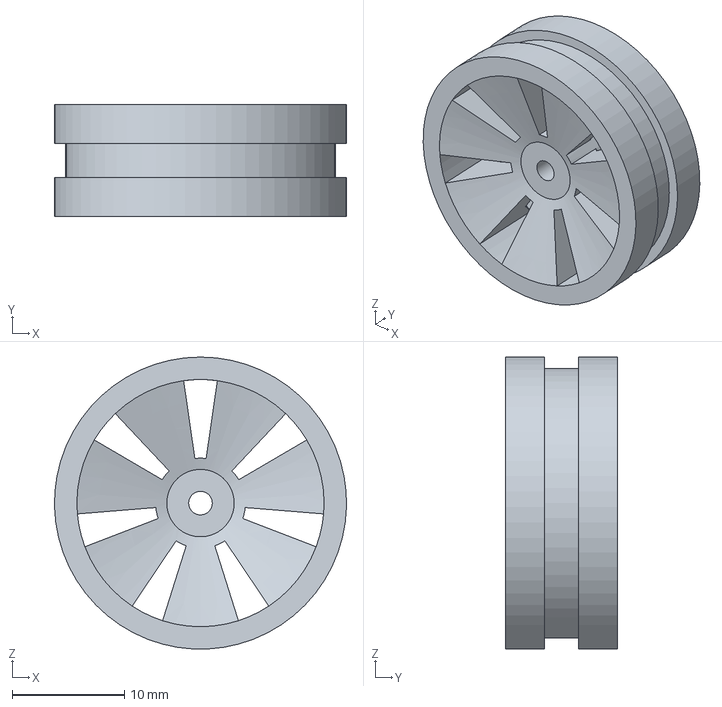
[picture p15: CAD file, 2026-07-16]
cars/v1/pneus/steps/Whells-Whells_26d_10l_V1.step
26.0 x 10.0 x 26.0 mm

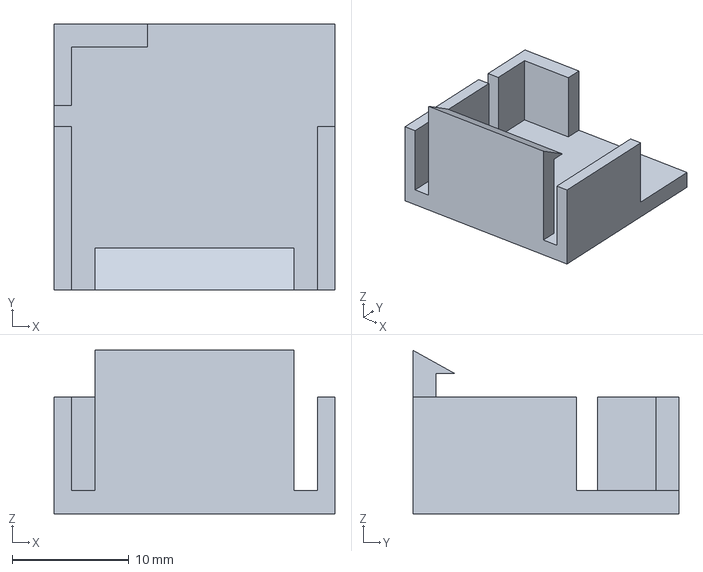
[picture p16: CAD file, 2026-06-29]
3dmodels/servos/GH-S37D/Encapsulamento-GH-S37D-SuportSemSuporteParafusos.3mf
24.1 x 22.8 x 14.0 mm

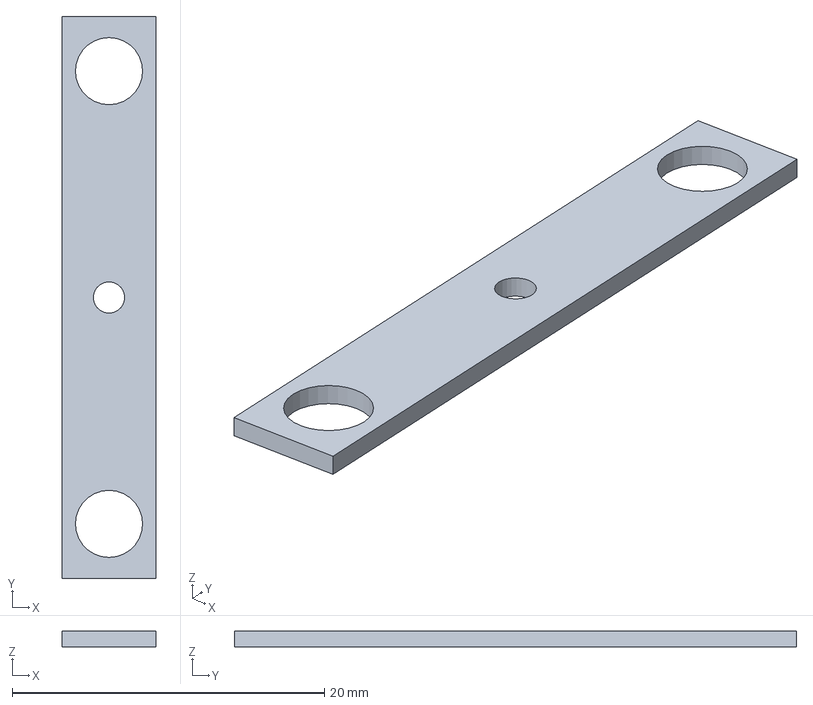
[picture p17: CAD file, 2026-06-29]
blue-car-1_32/prints/BlueCar132Carcass-TampaDirecao.3mf
6.00 x 36.0 x 1.00 mm

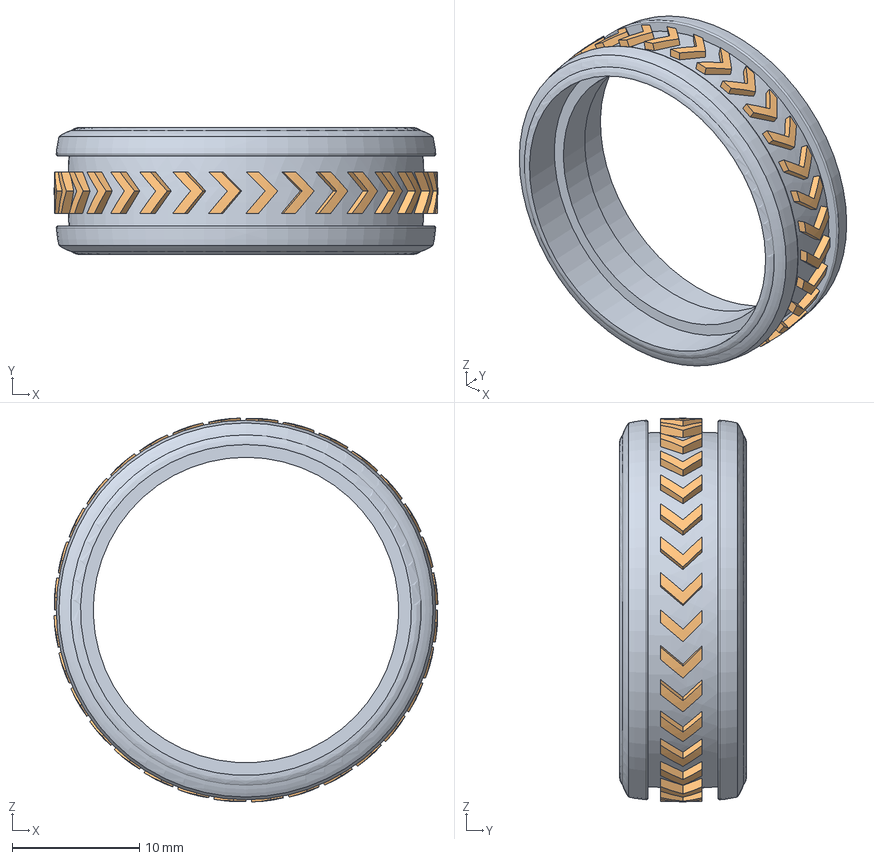
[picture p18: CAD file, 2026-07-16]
cars/v1/pneus/steps/Tires-Tire_2a_10l_V1.step
30.2 x 10.00 x 30.2 mm

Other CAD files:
cars/v1/pneus/Whells.FCStd
3dmodels/bears/MR52ZZ 2x5x2.5mm-Body.step
cars/v1/chassis/HubCarrier.FCStd
cars/v1/chassis/steps/WhellHub-WhellHubV1.step
3dmodels/motors/8520 Coreless Motor v3.f3d
3dmodels/servos/GH-S37D/Encapsulamento-GH-S37D-Suport.3mf
3dmodels/servos/GH-S37D/Encapsulamento.FCStd
3dmodels/servos/GH-S37D/Gh-S37D Servo.3MF
3dmodels/servos/GH-S37D/Gh-S37D Servo.SLDPRT
3dmodels/servos/GH-S37D/Gh-S37D Servo.STL
3dmodels/servos/Mini 2g Servo Motor/Mini 2g Servo Motor.f3d
blue-car-1_32/prints/BlueCar132Carcass-BaseEncaixe.3mf
blue-car-1_32/prints/BlueCar132Carcass-CuboDirecaoRodaDireita.3mf
cars/v1/chassis/SteeringKnuckle.FCStd
cars/v1/pneus/Tires.FCStd

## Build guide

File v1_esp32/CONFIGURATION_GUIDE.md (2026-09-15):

# RC Control Project Configuration Guide

## Overview
This project uses compile-time feature flags to enable/disable hardware and software features based on your specific board configuration.

## Quick Configuration

### For Boards WITHOUT Camera (Current Setup)
No changes needed. The default configuration in `project_config.h` is:
```c
#define ENABLE_CAMERA_SUPPORT       0   // Disabled
#define ENABLE_SERVO_CONTROL        1   // Enabled
#define ENABLE_LED_CONTROL          1   // Enabled
#define ENABLE_MOTOR_CONTROL        1   // Enabled
```

### For Boards WITH Camera (ESP32-CAM)
1. Edit `main/inc/project_config.h`:
```c
#define ENABLE_CAMERA_SUPPORT       1   // Enable camera
```

2. Uncomment camera dependency in `main/idf_component.yml`:
```yaml
dependencies:
  espressif/esp32-camera: "*"   # Uncomment this line
  idf: ">=4.1.0"
```

3. Ensure PSRAM is enabled in sdkconfig:
```bash
idf.py menuconfig
# Component config → ESP PSRAM → Enable support for external PSRAM
```

## Available Features

| Feature | Config Flag | Description |
|---|---|---|
| Camera Streaming | `ENABLE_CAMERA_SUPPORT` | Video stream via `/video` endpoint |
| Servo Control | `ENABLE_SERVO_CONTROL` | PWM servo control for steering |
| LED Control | `ENABLE_LED_CONTROL` | Horn/Light LED indicators |
| Motor Control | `ENABLE_MOTOR_CONTROL` | Motor speed control (future) |
| OTA Updates | `ENABLE_OTA_UPDATES` | Firmware update via web |
| WiFi Config | `ENABLE_WIFI_CONFIG` | WiFi setup via web interface |
| Debug Logging | `ENABLE_DEBUG_LOGGING` | Verbose debug output |

## Benefits of This Approach

### ✅ Advantages:
- **Clean compilation**: Only needed code is compiled
- **Smaller binary**: Unused features don't consume flash
- **Better performance**: No runtime checks for disabled features
- **Easy configuration**: Single header file controls all features
- **Board-specific builds**: Same codebase works on different hardware
- **Dependency management**: Only required libraries are included

### 🔧 Configuration Steps:

1. **Edit Features**: Modify `main/inc/project_config.h`
2. **Update Dependencies**: Edit `main/idf_component.yml` if camera is enabled
3. **Clean Build**: `idf.py fullclean`
4. **Rebuild**: `idf.py build`
5. **Flash**: `idf.py flash`

## Validation

The system automatically validates configurations:
- Warns if camera enabled without PSRAM
- Suggests enabling related features
- Sets appropriate log levels

## Example Configurations

### Minimal RC Car (No Camera)
```c
#define ENABLE_CAMERA_SUPPORT       0
#define ENABLE_SERVO_CONTROL        1
#define ENABLE_LED_CONTROL          1
#define ENABLE_MOTOR_CONTROL        1
#define ENABLE_OTA_UPDATES          1
#define ENABLE_DEBUG_LOGGING        0
```

### Full-Featured ESP32-CAM Car
```c
#define ENABLE_CAMERA_SUPPORT       1
#define ENABLE_SERVO_CONTROL        1
#define ENABLE_LED_CONTROL          1
#define ENABLE_MOTOR_CONTROL        1
#define ENABLE_OTA_UPDATES          1
#define ENABLE_DEBUG_LOGGING        1
```

### Testing/Development Setup
```c
#define ENABLE_CAMERA_SUPPORT       0
#define ENABLE_SERVO_CONTROL        1
#define ENABLE_LED_CONTROL          1
#define ENABLE_MOTOR_CONTROL        0  // Disabled for testing
#define ENABLE_OTA_UPDATES          1
#define ENABLE_DEBUG_LOGGING        1
```

## Runtime Behavior

When features are disabled:
- **Camera**: `/video` endpoint not registered, no streaming code compiled
- **Servo**: Commands logged but no PWM generated
- **LEDs**: Commands logged but no GPIO control
- **Motor**: Commands logged but no motor control
- **OTA**: No OTA handlers registered

This provides graceful degradation and clear feedback about what's enabled.

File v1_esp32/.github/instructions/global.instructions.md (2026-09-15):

---
description: Informações geral sobre a workspace e usabilidade
---

Ao usar a tool brave_search sempre faça apenas uma requisição por vez.

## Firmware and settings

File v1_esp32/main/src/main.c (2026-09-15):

#include <esp_log.h>
//#include "../../../../v5.2/esp-idf/components/soc/esp32c2/include/soc/rtc_cntl_reg.h"

#include "project_config.h"
#include "config.h"
#include "net.h"
#include "ota.h"

#if ENABLE_LED_CONTROL
#include "led_control.h"
#endif

#if ENABLE_SERVO_CONTROL
#include "servo_control.h"
#endif

#if ENABLE_BATTERY_MONITORING
#include "battery_monitor.h"
#endif

#if ENABLE_MOTOR_CONTROL
#include "motor_control.h"
#endif

// #include <sys/unistd.h>
// #include "esp_log.h"
// #include "esp_system.h"

// extern const uint8_t index_html_start[] asm("_binary_wwwroot_index_html_start");
// extern const uint8_t index_html_end[]   asm("_binary_wwwroot_index_html_end");
// extern const uint8_t index_html_start[] asm("_binary_index_html_start");
// extern const uint8_t index_html_end[]   asm("_binary_index_html_end");

void app_main(void)
{
    //TODO: remove this line and fix error: Brownout detector was triggered
    //WRITE_PERI_REG(RTC_CNTL_BROWN_OUT_REG, 0);

    // const size_t index_html_size = (index_html_end - index_html_start);
    // ESP_LOGI("test", "file size: %d", index_html_size);

    config_init();

#if ENABLE_LED_CONTROL
    led_control_init();
#endif

#if ENABLE_SERVO_CONTROL
    servo_control_init();
#endif

#if ENABLE_BATTERY_MONITORING
    battery_monitor_init();
#endif

#if ENABLE_MOTOR_CONTROL
    motor_control_init();
#endif

#if ENABLE_OTA_UPDATES
    ota_init();
#endif

    net_init();

#if ENABLE_BATTERY_MONITORING
    battery_monitor_start_task();
#endif

    // config_data_t config_data = config_load();

    // ESP_LOGI(TAG, "Count: %d!\n", config_data.count++);

    // config_save(config_data);
}

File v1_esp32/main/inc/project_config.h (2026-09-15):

#ifndef __PROJECT_CONFIG_H__
#define __PROJECT_CONFIG_H__

/**
 * @file project_config.h
 * @brief Project feature configuration
 * 
 * This file contains compile-time feature flags for the RC Control project.
 * Enable or disable features by commenting/uncommenting the #define statements.
 */

// =============================================================================
// HARDWARE FEATURE CONFIGURATION
// =============================================================================

/**
 * @brief Enable camera support
 * 
 * Set to 1 to enable camera streaming functionality.
 * Set to 0 to disable camera support (for boards without camera).
 * 
 * Uncomment the line on file idf_component.yml
 *   # espressif/esp32-camera: "*"
 * Uncomment the lines between CONFIGURATION FOR CAM in file sdkconfig
 * 
 * Requirements when enabled:
 * - ESP32-CAM or compatible board with camera module
 * - PSRAM recommended for better performance
 * - esp32-camera component dependency
 */
#define ENABLE_CAMERA_SUPPORT       0   // 0 = Disabled, 1 = Enabled

/**
 * @brief Enable servo motor control
 * 
 * Set to 1 to enable servo motor control for steering.
 * Set to 0 to disable servo support.
 */
#define ENABLE_SERVO_CONTROL        1   // 0 = Disabled, 1 = Enabled

/**
 * @brief Enable LED control
 * 
 * Set to 1 to enable LED control (horn/light indicators).
 * Set to 0 to disable LED support.
 */
#define ENABLE_LED_CONTROL          1   // 0 = Disabled, 1 = Enabled

/**
 * @brief Enable battery monitoring
 * 
 * Set to 1 to enable battery voltage monitoring via ADC.
 * Set to 0 to disable battery monitoring.
 * Configure details in battery_monitor.h
 */
#define ENABLE_BATTERY_MONITORING   1   // 0 = Disabled, 1 = Enabled

/**
 * @brief Enable motor speed control
 * 
 * Set to 1 to enable motor speed control functionality.
 * Set to 0 to disable motor control (for testing without motor).
 */
#define ENABLE_MOTOR_CONTROL        1   // 0 = Disabled, 1 = Enabled

// =============================================================================
// SOFTWARE FEATURE CONFIGURATION
// =============================================================================

/**
 * @brief Enable OTA (Over-The-Air) updates
 * 
 * Set to 1 to enable firmware update via web interface.
 * Set to 0 to disable OTA support.
 */
#define ENABLE_OTA_UPDATES          1   // 0 = Disabled, 1 = Enabled

/**
 * @brief Enable WiFi configuration web interface
 * 
 * Set to 1 to enable WiFi configuration via web interface.
 * Set to 0 to use hardcoded WiFi settings.
 */
#define ENABLE_WIFI_CONFIG          1   // 0 = Disabled, 1 = Enabled

/**
 * @brief Enable debug logging
 * 
 * Set to 1 to enable verbose debug logging.
 * Set to 0 for production builds with minimal logging.
 */
#define ENABLE_DEBUG_LOGGING        1   // 0 = Disabled, 1 = Enabled

// =============================================================================
// VALIDATION AND DERIVED CONFIGURATIONS
// =============================================================================

// Validate camera configuration
#if ENABLE_CAMERA_SUPPORT && !defined(CONFIG_SPIRAM)
    #warning "Camera support enabled but PSRAM not configured. Performance may be limited."
#endif

// Feature dependency validation
#if ENABLE_SERVO_CONTROL && !ENABLE_MOTOR_CONTROL
    #warning "Servo control enabled but motor control disabled. Consider enabling both for full RC functionality."
#endif

// Debug configuration
#if ENABLE_DEBUG_LOGGING
    #define LOG_LEVEL ESP_LOG_DEBUG
#else
    #define LOG_LEVEL ESP_LOG_INFO
#endif

#endif // __PROJECT_CONFIG_H__

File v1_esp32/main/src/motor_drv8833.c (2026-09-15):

#include "project_config.h"

#if ENABLE_MOTOR_CONTROL && (MOTOR_ACTIVE_DRIVER == MOTOR_DRIVER_DRV8833)

#include <esp_log.h>
#include <esp_err.h>
#include <driver/ledc.h>
#include <driver/gpio.h>
#include <string.h>
#include "motor_drv8833.h"

static const char *TAG = "drv8833";
static bool drv8833_initialized = false;
static motor_state_t drv8833_state = {
    .speed = 0,
    .mode = MOTOR_MODE_FREE,
    .enabled = false
};

// =============================================================================
// PRIVATE FUNCTIONS
// =============================================================================

/**
 * @brief Configure GPIO pins for DRV8833
 * @return ESP_OK on success, error code on failure
 */
static esp_err_t configure_gpio(void)
{
    gpio_config_t io_conf = {
        .intr_type = GPIO_INTR_DISABLE,
        .mode = GPIO_MODE_OUTPUT,
        .pin_bit_mask = (1ULL << DRV8833_IN1_PIN) | (1ULL << DRV8833_IN2_PIN),
        .pull_down_en = GPIO_PULLDOWN_DISABLE,
        .pull_up_en = GPIO_PULLUP_DISABLE,
    };

    esp_err_t ret = gpio_config(&io_conf);
    if (ret != ESP_OK) {
        ESP_LOGE(TAG, "Failed to configure GPIO pins: %s", esp_err_to_name(ret));
        return ret;
    }

    // Set initial state to free mode
    gpio_set_level(DRV8833_IN1_PIN, DRV8833_FREE_MODE_LOW ? 0 : 1);
    gpio_set_level(DRV8833_IN2_PIN, DRV8833_FREE_MODE_LOW ? 0 : 1);

    ESP_LOGI(TAG, "GPIO pins configured - IN1: GPIO%d, IN2: GPIO%d", 
             DRV8833_IN1_PIN, DRV8833_IN2_PIN);
    return ESP_OK;
}

/**
 * @brief Configure LEDC timers and channels for PWM
 * @return ESP_OK on success, error code on failure
 */
static esp_err_t configure_ledc(void)
{
    // Configure LEDC timer
    ledc_timer_config_t ledc_timer = {
        .duty_resolution = DRV8833_LEDC_DUTY_RES,
        .freq_hz = DRV8833_LEDC_FREQUENCY,
        .speed_mode = DRV8833_LEDC_MODE,
        .timer_num = DRV8833_LEDC_TIMER,
        .clk_cfg = LEDC_AUTO_CLK,
    };

    esp_err_t ret = ledc_timer_config(&ledc_timer);
    if (ret != ESP_OK) {
        ESP_LOGE(TAG, "Failed to configure LEDC timer: %s", esp_err_to_name(ret));
        return ret;
    }

    // Configure LEDC channel for IN1
    ledc_channel_config_t ledc_channel_in1 = {
        .channel = DRV8833_LEDC_IN1_CHANNEL,
        .duty = 0,
        .gpio_num = DRV8833_IN1_PIN,
        .speed_mode = DRV8833_LEDC_MODE,
        .hpoint = 0,
        .timer_sel = DRV8833_LEDC_TIMER,
        .flags.output_invert = 0
    };

    ret = ledc_channel_config(&ledc_channel_in1);
    if (ret != ESP_OK) {
        ESP_LOGE(TAG, "Failed to configure LEDC channel IN1: %s", esp_err_to_name(ret));
        return ret;
    }

    // Configure LEDC channel for IN2
    ledc_channel_config_t ledc_channel_in2 = {
        .channel = DRV8833_LEDC_IN2_CHANNEL,
        .duty = 0,
        .gpio_num = DRV8833_IN2_PIN,
        .speed_mode = DRV8833_LEDC_MODE,
        .hpoint = 0,
        .timer_sel = DRV8833_LEDC_TIMER,
        .flags.output_invert = 0
    };

    ret = ledc_channel_config(&ledc_channel_in2);
    if (ret != ESP_OK) {
        ESP_LOGE(TAG, "Failed to configure LEDC channel IN2: %s", esp_err_to_name(ret));
        return ret;
    }

    ESP_LOGI(TAG, "LEDC configured - Timer: %d, Frequency: %dHz, Resolution: %d-bit",
             DRV8833_LEDC_TIMER, DRV8833_LEDC_FREQUENCY, (1 << DRV8833_LEDC_DUTY_RES));

    return ESP_OK;
}

/**
 * @brief Set PWM duty cycle for a channel
 * @param channel LEDC channel
 * @param duty_percent Duty cycle percentage (0-100)
 * @return ESP_OK on success, error code on failure
 */
static esp_err_t set_pwm_duty(ledc_channel_t channel, int duty_percent)
{
    if (duty_percent < 0) duty_percent = 0;
    if (duty_percent > 100) duty_percent = 100;

    uint32_t duty = (duty_percent * DRV8833_MAX_DUTY) / 100;
    
    esp_err_t ret = ledc_set_duty(DRV8833_LEDC_MODE, channel, duty);
    if (ret != ESP_OK) {
        return ret;
    }

    return ledc_update_duty(DRV8833_LEDC_MODE, channel);
}

/**
 * @brief Apply motor control signals to DRV8833
 * @param mode Motor mode
 * @param speed_percent Speed percentage (0-100) for PWM modes
 * @return ESP_OK on success, error code on failure
 */
static esp_err_t apply_motor_control(motor_mode_t mode, int speed_percent)
{
    esp_err_t ret = ESP_OK;

    switch (mode) {
        case MOTOR_MODE_FORWARD:
            // Forward: IN1=PWM, IN2=LOW
            ret = set_pwm_duty(DRV8833_LEDC_IN1_CHANNEL, speed_percent);
            if (ret == ESP_OK) {
                ret = set_pwm_duty(DRV8833_LEDC_IN2_CHANNEL, 0);
            }
            ESP_LOGD(TAG, "Forward mode: IN1=%d%%, IN2=0%%", speed_percent);
            break;

        case MOTOR_MODE_REVERSE:
            // Reverse: IN1=LOW, IN2=PWM
            ret = set_pwm_duty(DRV8833_LEDC_IN1_CHANNEL, 0);
            if (ret == ESP_OK) {
                ret = set_pwm_duty(DRV8833_LEDC_IN2_CHANNEL, speed_percent);
            }
            ESP_LOGD(TAG, "Reverse mode: IN1=0%%, IN2=%d%%", speed_percent);
            break;

        case MOTOR_MODE_BRAKE:
            // Brake mode: Based on configuration
            if (DRV8833_BRAKE_MODE_HIGH) {
                // IN1=HIGH, IN2=HIGH
                ret = set_pwm_duty(DRV8833_LEDC_IN1_CHANNEL, 100);
                if (ret == ESP_OK) {
                    ret = set_pwm_duty(DRV8833_LEDC_IN2_CHANNEL, 100);
                }
                ESP_LOGD(TAG, "Brake mode: IN1=HIGH, IN2=HIGH");
            } else {
                // IN1=LOW, IN2=LOW
                ret = set_pwm_duty(DRV8833_LEDC_IN1_CHANNEL, 0);
                if (ret == ESP_OK) {
                    ret = set_pwm_duty(DRV8833_LEDC_IN2_CHANNEL, 0);
                }
                ESP_LOGD(TAG, "Brake mode: IN1=LOW, IN2=LOW");
            }
            break;

        case MOTOR_MODE_FREE:
            // Free mode: Based on configuration
            if (DRV8833_FREE_MODE_LOW) {
                // IN1=LOW, IN2=LOW
                ret = set_pwm_duty(DRV8833_LEDC_IN1_CHANNEL, 0);
                if (ret == ESP_OK) {
                    ret = set_pwm_duty(DRV8833_LEDC_IN2_CHANNEL, 0);
                }
                ESP_LOGD(TAG, "Free mode: IN1=LOW, IN2=LOW");
            } else {
                // IN1=HIGH, IN2=HIGH
                ret = set_pwm_duty(DRV8833_LEDC_IN1_CHANNEL, 100);
                if (ret == ESP_OK) {
                    ret = set_pwm_duty(DRV8833_LEDC_IN2_CHANNEL, 100);
                }
                ESP_LOGD(TAG, "Free mode: IN1=HIGH, IN2=HIGH");
            }
            break;

        default:
            ESP_LOGE(TAG, "Unknown motor mode: %d", mode);
            return ESP_ERR_INVALID_ARG;
    }

    return ret;
}

// =============================================================================
// DRIVER INTERFACE IMPLEMENTATION
// =============================================================================
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

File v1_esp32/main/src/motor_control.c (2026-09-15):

#include "project_config.h"

#if ENABLE_MOTOR_CONTROL

#include <esp_log.h>
#include <esp_err.h>
#include <string.h>
#include "motor_control.h"

static const char *TAG = "motor_control";
static const motor_driver_interface_t *active_driver = NULL;
static motor_state_t current_state = {
    .speed = 0,
    .mode = MOTOR_MODE_FREE,
    .enabled = false
};
static bool motor_initialized = false;

// =============================================================================
// PRIVATE FUNCTIONS
// =============================================================================

/**
 * @brief Validate speed parameter
 * @param speed Speed value to validate
 * @return true if valid, false otherwise
 */
static bool validate_speed(int speed)
{
    return (speed >= -100 && speed <= 100);
}

/**
 * @brief Convert speed to motor mode and absolute speed
 * @param speed Input speed (-100 to +100)
 * @param mode Output motor mode
 * @param abs_speed Output absolute speed (0 to 100)
 */
static void speed_to_mode(int speed, motor_mode_t *mode, int *abs_speed)
{
    // Validate required parameter
    if (!mode) {
        ESP_LOGE(TAG, "speed_to_mode: mode parameter cannot be NULL");
        return;
    }
    
    if (speed > 0) {
        *mode = MOTOR_MODE_FORWARD;
        if (abs_speed) *abs_speed = speed;
    } else if (speed < 0) {
        *mode = MOTOR_MODE_REVERSE;
        if (abs_speed) *abs_speed = -speed;
    } else {
        *mode = MOTOR_MODE_BRAKE;  // Use brake for stop
        if (abs_speed) *abs_speed = 0;
    }
}

// =============================================================================
// PUBLIC API IMPLEMENTATION
// =============================================================================

esp_err_t motor_control_init(void)
{
    if (motor_initialized) {
        ESP_LOGW(TAG, "Motor control already initialized");
        return ESP_OK;
    }

    ESP_LOGI(TAG, "Initializing motor control HAL");

    // Get the appropriate driver interface based on configuration
#if MOTOR_ACTIVE_DRIVER == MOTOR_DRIVER_DRV8833
    active_driver = drv8833_get_interface();
#else
    ESP_LOGE(TAG, "No motor driver configured");
    return ESP_ERR_NOT_SUPPORTED;
#endif

    if (active_driver == NULL) {
        ESP_LOGE(TAG, "Failed to get motor driver interface");
        return ESP_ERR_INVALID_STATE;
    }

    // Validate required driver functions
    if (!active_driver->init || !active_driver->name) {
        ESP_LOGE(TAG, "Driver interface incomplete - missing required functions");
        active_driver = NULL;
        return ESP_ERR_INVALID_STATE;
    }

    ESP_LOGI(TAG, "Using motor driver: %s", active_driver->name);

    // Initialize the driver
    esp_err_t ret = active_driver->init();
    if (ret != ESP_OK) {
        ESP_LOGE(TAG, "Failed to initialize motor driver: %s", esp_err_to_name(ret));
        active_driver = NULL;
        return ret;
    }

    // Initialize motor state
    current_state.speed = 0;
    current_state.mode = MOTOR_MODE_FREE;
    current_state.enabled = true;

    motor_initialized = true;
    ESP_LOGI(TAG, "Motor control HAL initialized successfully");

    return ESP_OK;
}

esp_err_t motor_control_deinit(void)
{
    if (!motor_initialized) {
        ESP_LOGW(TAG, "Motor control not initialized");
        return ESP_OK;
    }

    ESP_LOGI(TAG, "Deinitializing motor control HAL");

    if (active_driver && active_driver->deinit) {
        esp_err_t ret = active_driver->deinit();
        if (ret != ESP_OK) {
            ESP_LOGW(TAG, "Warning: Driver deinit failed: %s", esp_err_to_name(ret));
        }
    }

    active_driver = NULL;
    current_state.enabled = false;
    motor_initialized = false;

    ESP_LOGI(TAG, "Motor control HAL deinitialized");
    return ESP_OK;
}

esp_err_t motor_control_set_speed(int speed)
{
    if (!motor_initialized || !active_driver) {
        ESP_LOGE(TAG, "Motor control not initialized");
        return ESP_ERR_INVALID_STATE;
    }

    if (!validate_speed(speed)) {
        ESP_LOGE(TAG, "Invalid speed value: %d (must be -100 to +100)", speed);
        return ESP_ERR_INVALID_ARG;
    }

    ESP_LOGI(TAG, "Setting motor speed: %d", speed);

    // Use driver's set_speed if available, otherwise convert to mode
    esp_err_t ret;
    if (active_driver->set_speed) {
        ret = active_driver->set_speed(speed);
    } else {
        // Fallback: convert speed to mode
        motor_mode_t mode;
        int abs_speed;
        speed_to_mode(speed, &mode, &abs_speed);
        ret = active_driver->set_mode(mode);
    }

    if (ret == ESP_OK) {
        current_state.speed = speed;
        speed_to_mode(speed, &current_state.mode, NULL);
    } else {
        ESP_LOGE(TAG, "Failed to set motor speed: %s", esp_err_to_name(ret));
    }

    return ret;
}

esp_err_t motor_control_set_mode(motor_mode_t mode)
{
    if (!motor_initialized || !active_driver) {
        ESP_LOGE(TAG, "Motor control not initialized");
        return ESP_ERR_INVALID_STATE;
    }

    if (!active_driver->set_mode) {
        ESP_LOGE(TAG, "Driver does not support set_mode");
        return ESP_ERR_NOT_SUPPORTED;
    }

    ESP_LOGI(TAG, "Setting motor mode: %d", mode);

    esp_err_t ret = active_driver->set_mode(mode);
    if (ret == ESP_OK) {
        current_state.mode = mode;
        // Reset speed when setting mode directly
        if (mode == MOTOR_MODE_BRAKE || mode == MOTOR_MODE_FREE) {
            current_state.speed = 0;
        }
    } else {
        ESP_LOGE(TAG, "Failed to set motor mode: %s", esp_err_to_name(ret));
    }

    return ret;
}

esp_err_t motor_control_stop(void)
{
    if (!motor_initialized || !active_driver) {
        ESP_LOGE(TAG, "Motor control not initialized");
        return ESP_ERR_INVALID_STATE;
    }

    ESP_LOGI(TAG, "Stopping motor");

    esp_err_t ret;
    if (active_driver->stop) {
        ret = active_driver->stop();
    } else {
        // Fallback to brake mode
        ret = active_driver->set_mode(MOTOR_MODE_BRAKE);
    }

    if (ret == ESP_OK) {
        current_state.speed = 0;
        current_state.mode = MOTOR_MODE_BRAKE;
    } else {
        ESP_LOGE(TAG, "Failed to stop motor: %s", esp_err_to_name(ret));
    }

    return ret;
}

esp_err_t motor_control_get_state(motor_state_t *state)
{
    if (state == NULL) {
        return ESP_ERR_INVALID_ARG;
    }

    if (!motor_initialized || !active_driver) {
        ESP_LOGE(TAG, "Motor control not initialized");
        return ESP_ERR_INVALID_STATE;
    }

    // Try to get state from driver first
    if (active_driver->get_state) {
        esp_err_t ret = active_driver->get_state(state);
        if (ret == ESP_OK) {
            return ret;
        }
        // Fall through to use cached state if driver fails
    }

    // Use cached state
    memcpy(state, &current_state, sizeof(motor_state_t));
    return ESP_OK;
}
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

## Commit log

2025-07-27 OTA first step
    [partitions.csv]
2025-07-27 speed button working
2025-07-27 buttons light and horn working
2025-07-27 wheels working
2025-09-19 servo working
2026-06-15 3dmodels and improves
    [8520 Coreless Brshed motor.step, 8520 Coreless Motor v3.f3d, BlueCar132Carcass.FCStd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]
2026-06-29 moving esp32 project to v1_esp32
    [partitions.csv]
2026-07-16 chassis v1
    [ChassiAssembly.FCStd, HubCarrier.FCStd, MR52ZZ 2x5x2.5mm-Body.step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]
2026-09-15 a lot
    [8520 Coreless Brshed motor.step, Gh-S37D Servo.STEP, Mini 2g Servo Motor.step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]
